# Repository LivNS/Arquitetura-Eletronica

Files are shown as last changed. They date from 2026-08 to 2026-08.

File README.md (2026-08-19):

# Carrinho-robô — Project-based Maker Lab (FIAP)

Engenharia de Software, disciplina Project-based Maker Lab (Profª Dra. Gedeane G. S. Kenshima).

**Integrantes:** 
- Debora da Silva Amaral - RM 550412 
- Eduardo Pielich - RM 99767 
- Livia Namba Seraphim - RM 97819 

## O que é

Carrinho-robô de duas rodas com tração diferencial, controlado sem fio pelo celular e com parada automática por sensor ultrassônico.

- **Plataforma:** ESP32 DevKit V1
- **Controle:** Wi-Fi — o ESP32 sobe um servidor web e o celular controla pelo navegador
- **Sensor:** HC-SR04 (para automaticamente a menos de 20 cm de um obstáculo)
- **Driver:** ponte H L298N
- **Alimentação:** 2 × 18650 (7,4 V) com regulador step-down 5 V para a lógica

## Estrutura

```
/hardware
  /arquitetura      diagramas de blocos, alimentação e layout físico (SVG)
  /componentes      lista de componentes, pinagem e consumo
/cad
  /stl              chassi exportado para impressão/corte (v0.1, v0.2 …)
  /fonte            modelo paramétrico em OpenSCAD
/src
  codigo.ino        firmware (ESP32 + Wi-Fi + ultrassônico)
/docs
  changelog-chassi.md    o que mudou da V0.1 para a V0.2
  mudancas-codigo.md     o que o grupo acrescentou ao código da aula
  testes.md              roteiro de teste incremental
  /registro-testes       fotos e vídeos dos testes
```

## Arquitetura

| Diagrama | Arquivo |
|---|---|
| Blocos (sinais e pinos) | [`hardware/arquitetura/diagrama-blocos.svg`](hardware/arquitetura/diagrama-blocos.svg) |
| Alimentação | [`hardware/arquitetura/diagrama-alimentacao.svg`](hardware/arquitetura/diagrama-alimentacao.svg) |
| Layout físico e cabos | [`hardware/arquitetura/layout-fisico.svg`](hardware/arquitetura/layout-fisico.svg) |

## Como rodar

1. Instalar a IDE Arduino e adicionar o suporte ao ESP32 (Gerenciador de Placas → `esp32` by Espressif).
2. Selecionar a placa **ESP32 Dev Module** e a porta COM correspondente.
3. Abrir `/src/codigo.ino` e preencher `ssid` e `password` com a rede Wi-Fi **de 2,4 GHz** (o ESP32 não enxerga 5 GHz).
4. Gravar, abrir o monitor serial em **115200** e anotar o IP que aparece.
5. Com o celular na mesma rede, acessar `http://<IP>` no navegador.

Antes do primeiro teste com os motores, seguir o roteiro de [`docs/testes.md`](docs/testes.md) com as rodas fora do chão.

## Escolha do controle sem fio

A aula apresentou três caminhos (Wi-Fi, ESP32-BLE e Arduino+HC-05). O grupo adotou o **controle via Wi-Fi** (opção 1, slide 7): não exige instalar nenhum app no celular — basta abrir o IP do ESP32 no navegador — e permite exibir a leitura do sensor na mesma tela do controle.

O código parte do que foi apresentado nos slides 8 a 13; os acréscimos do grupo estão marcados com `// [GRUPO]` e listados em [`docs/mudancas-codigo.md`](docs/mudancas-codigo.md).

## Estado atual

- [x] Chassi V0.2 definido
- [x] Diagramas de blocos e alimentação
- [x] Firmware com movimento, Wi-Fi e sensor
- [x] Sensor ultrassônico integrado ao código
- [ ] Testes incrementais registrados (`docs/testes.md`)
- [ ] STL da V0.2 exportado para `/cad/stl`

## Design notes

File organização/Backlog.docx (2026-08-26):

Backlog

Project-based Maker Lab — FIAP

Lista de tarefas derivadas do MoSCoW, organizadas para alimentar o Kanban. As colunas Responsável e Status devem ser preenchidas conforme cada item for assumido pelo time. Os identificadores (IDs) devem permanecer estáveis — sem renumeração — para preservar o histórico do projeto.

Convenção de status: A fazer · Em andamento · Bloqueada · Em revisão · Concluída

# Hardware

ID | Tarefa | Prioridade | Responsável | Status | Observação
HW-01 | Definir lista final de componentes e conferir com o kit recebido | Must | Debora | A fazer | ver lista-componentes.md
HW-02 | Montar circuito na bancada (sem chassi) para validar ligação | Must | Debora | A fazer | pré-requisito do MVP
HW-03 | Exportar e imprimir/cortar o chassi V0.2 | Must | Livia | A fazer | depende de CAD-01
HW-04 | Fixar motores, roda boba e suporte de bateria no chassi | Must | Debora | A fazer | depende de HW-03
HW-05 | Montar divisor resistivo do ECHO do HC-SR04 | Must | Eduardo | A fazer | protoboard pequena
HW-06 | Organizar cabos (canaletas, abraçadeiras) | Should | Livia | A fazer | depende de HW-04
HW-07 | Medir autonomia real da bateria | Should | Eduardo | A fazer | depende do carrinho montado
HW-08 | Avaliar posição de um segundo sensor (lateral) | Could | Debora | A fazer | apenas se houver tempo disponível

# CAD

ID | Tarefa | Prioridade | Responsável | Status | Observação
CAD-01 | Revisar chassi V0.1 → V0.2 conforme changelog-chassi.md | Must | Livia | Concluída | fonte: cad/fonte/chassi_v0.2.scad
CAD-02 | Exportar STL da V0.2 | Must | Debora | A fazer | salvar em cad/stl/chassi_v0.2.stl
CAD-03 | Conferir furação depois da primeira montagem física | Should | Eduardo | A fazer | depende de HW-04

# Firmware

ID | Tarefa | Prioridade | Responsável | Status | Observação
FW-01 | Adaptar código-base do slide (Wi-Fi) com credenciais do grupo | Must | Eduardo | Concluída | src/codigo.ino
FW-02 | Integrar leitura do HC-SR04 | Must | Eduardo | Concluída | marcado com // [GRUPO]
FW-03 | Implementar parada automática < 20 cm | Must | Eduardo | Concluída | só bloqueia o comando FRENTE
FW-04 | Implementar failsafe de conexão | Should | Eduardo | Concluída | timeout de 1,5 s
FW-05 | Exibir distância na página de controle | Should | Debora | Concluída | rota /distancia
FW-06 | Calibrar faixa de PWM mínimo (motor não sai do lugar) | Should | Debora | A fazer | depende de HW-02
FW-07 | Revisar mudancas-codigo.md para bater com o código final | Must | Eduardo | A fazer | atualizar antes de cada entrega

# Testes

ID | Tarefa | Prioridade | Responsável | Status | Observação
TST-01 | Executar os 15 passos de testes.md | Must | Debora | A fazer | depende de HW-02 e FW-01..05
TST-02 | Gravar vídeo/foto de cada passo em docs/registro-testes/ | Must | Livia | A fazer | mesmo ID do teste no nome do arquivo
TST-03 | Teste completo no chão com obstáculo real | Must | Debora | A fazer | depende de HW-04, HW-06

# Documentação e organização

ID | Tarefa | Prioridade | Responsável | Status | Observação
DOC-01 | Preencher README.md com integrantes e estado atual | Must | Livia | A fazer
DOC-02 | Preencher planilha de custos com preços reais | Must | Livia | A fazer | planilha-custos.xlsx
DOC-03 | Manter o Kanban atualizado a cada reunião do grupo | Should | Livia | A fazer | Kanban.docx
DOC-04 | Revisar MoSCoW antes da entrega final | Should | Livia | A fazer | ver seção Revisão

# Diretrizes de uso

- Toda nova tarefa recebe um identificador sequencial dentro de sua categoria (HW-09, FW-08, etc.).
- Ao assumir uma tarefa, o responsável deve atualizar o status neste documento e mover o cartão correspondente no Kanban.
- Tarefas com status Bloqueada devem indicar, na coluna Observação, o motivo do bloqueio.

Project-based Maker Lab — Carrinho-robô · página 1

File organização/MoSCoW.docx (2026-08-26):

MoSCoW — priorização das funcionalidades

Project-based Maker Lab — FIAP

Classificação de todas as funcionalidades previstas para o carrinho, com o objetivo de orientar a alocação do tempo do grupo. As funcionalidades Must compõem o MVP (ver MVP.docx); Should e Could serão desenvolvidas caso haja tempo disponível; Won't permanece documentado para que não seja esquecido nem rediscutido próximo ao prazo de entrega.

# Must have — requisitos obrigatórios

Funcionalidade | Justificativa
Motores respondem a FRENTE / RÉ / ESQUERDA / DIREITA / PARAR | Constitui o deslocamento do carrinho — sem essa funcionalidade não há projeto
Servidor Wi-Fi no ESP32 com página de controle | Forma de controle definida pelo grupo (slide 7, opção 1)
Leitura do sensor HC-SR04 | Entregável explícito da Aula 16
Parada automática abaixo de 20 cm | Requisito de segurança definido pelo grupo
Chassi montado e motores fixados | Sem estrutura física não há como realizar testes reais
Alimentação por bateria, sem depender de USB do computador | Necessária para que o carrinho se desloque livremente

# Should have — relevante, mas não impede a entrega

Funcionalidade | Justificativa
Controle de velocidade pelo slider | Já presente no código de referência da aula, com custo de manutenção baixo
Failsafe (interrupção ao perder conexão) | Reduz o risco de acidente durante a demonstração, ainda que não seja critério de avaliação direto
Organização de cabos com abraçadeiras e canaletas | Torna a montagem mais confiável e com melhor acabamento
Exibição da distância lida na própria página | Facilita a validação do sensor sem necessidade do monitor serial

# Could have — desejável, se houver tempo disponível

Funcionalidade | Justificativa
LED indicando status (conectado / obstáculo / parado) | Melhora a demonstração, sem impacto na funcionalidade principal
Segundo sensor (lateral ou traseiro) | Amplia a segurança, mas exige GPIOs adicionais e alteração no chassi
Registro do consumo de bateria em tempo real | Relevante, porém fora do escopo previsto pela disciplina
Alternativas de controle (BLE, HC-05) mantidas como referência | Documenta o processo de decisão do grupo, sem uso na entrega final

# Won't have — fora desta entrega

Funcionalidade | Motivo da exclusão
Navegação autônoma / desvio automático de rota | Fora do escopo abordado pela disciplina até o momento
Aplicativo dedicado, fora do navegador | O controle via Wi-Fi e navegador já atende ao requisito, sem custo adicional de desenvolvimento
Múltiplos sensores simultâneos | A complexidade de fiação e de GPIOs não se justifica dentro do prazo disponível
(a definir pelo grupo) | (a definir pelo grupo)

# Revisão

Esta classificação deve ser revisada a cada ciclo do Kanban. Itens Should/Could concluídos devem ser registrados no changelog; itens que não avançarem até a penúltima entrega serão automaticamente reclassificados como Won't.

Project-based Maker Lab — Carrinho-robô · página 1

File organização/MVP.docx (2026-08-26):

MVP do carrinho-robô

Project-based Maker Lab — FIAP

# Definição de MVP

O produto final do projeto consiste no carrinho em movimento, respondendo a comandos via Wi-Fi e interrompendo o deslocamento automaticamente ao se aproximar de um obstáculo. O MVP (Minimum Viable Product) corresponde ao menor subconjunto dessas funcionalidades que já demonstra a solução funcionando de ponta a ponta, ainda que sem acabamento — sem chassi definitivo e sem organização de cabos. Seu propósito é permitir uma demonstração antecipada da viabilidade técnica, de modo que eventuais problemas estruturais (por exemplo, motor sem torque suficiente, ou rede Wi-Fi indisponível no local da apresentação) sejam identificados com antecedência, e não na véspera da entrega final.

# Critério de produto minimamente funcional (MVP)

O MVP será considerado atingido quando, com o carrinho posicionado sobre a bancada (rodas suspensas, sem contato com o solo), as seguintes condições forem verificadas:

☐ Os dois motores giram nos dois sentidos, comandados pelo ESP32

☐ A página Wi-Fi é acessada pelo celular e os botões FRENTE / RÉ / ESQUERDA / DIREITA / PARAR respondem corretamente

☐ O sensor HC-SR04 realiza leituras estáveis de distância, compatíveis com medição feita por trena

☐ O carrinho interrompe o movimento automaticamente ao detectar obstáculo a menos de 20 cm, mesmo com o comando FRENTE ativo

Critério de aceite do MVP: é possível registrar um vídeo de até 30 segundos demonstrando as quatro condições acima, ainda que com fiação provisória e sem o chassi V0.2 impresso.

Data alvo: 20/09/2026

# Critério de conclusão

O projeto será considerado concluído quando, além do MVP, as seguintes condições forem atendidas:

☐ Chassi V0.2 (ou versão posterior) montado, com todos os componentes fixados

☐ Cabeamento organizado conforme hardware/arquitetura/layout-fisico.svg (canaletas, abraçadeiras)

☐ Roteiro completo de docs/testes.md executado e registrado em docs/registro-testes/

☐ Carrinho em funcionamento sobre piso real, percorrendo trajeto com pelo menos um obstáculo

☐ Autonomia da bateria medida e registrada em hardware/componentes/lista-componentes.md

☐ Repositório do GitHub com todas as pastas de /organização e /hardware devidamente preenchidas

☐ Apresentação/demonstração ensaiada previamente à data de entrega

Critério de aceite da versão final: um professor ou integrante de outro grupo consegue montar o carrinho e reproduzir o teste utilizando apenas as instruções do README, sem necessidade de esclarecimentos adicionais do grupo.

Data alvo: 20/09/2026

# Itens fora do escopo

Funcionalidades não abordadas em aula e que o grupo optou por não desenvolver nesta etapa, de modo a concentrar esforços no que será avaliado:

- Navegação autônoma sem intervenção humana
- Sensores adicionais (lateral, traseiro)
- Aplicativo dedicado, fora do navegador

Project-based Maker Lab — Carrinho-robô · página 1

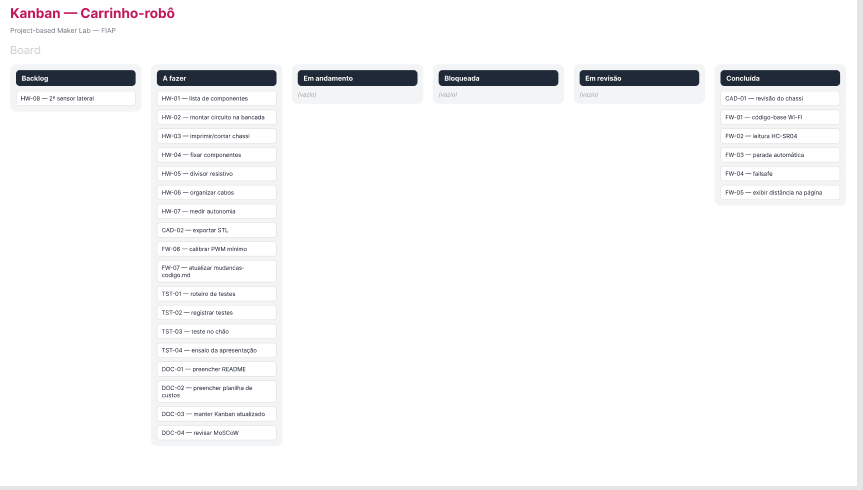
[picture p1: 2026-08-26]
organização/Kanban.png

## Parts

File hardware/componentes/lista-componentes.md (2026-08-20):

# Lista de componentes (BOM)

## 1. Eletrônica

| # | Componente | Modelo | Qtd | Tensão | Consumo típico | Função no projeto |
|---|---|---|---|---|---|---|
| 1 | Microcontrolador | ESP32 DevKit V1 (30 ou 38 pinos) | 1 | 5 V no VIN / 3,3 V lógica | ~80 mA (picos de 250 mA no Wi-Fi) | servidor web + controle |
| 2 | Driver de motor | Ponte H L298N | 1 | 5–35 V | ~36 mA + motores | aciona os dois motores |
| 3 | Sensor de distância | HC-SR04 | 1 | 5 V | ~15 mA | parada automática frontal |
| 4 | Regulador | step-down MP1584 ou LM2596 | 1 | entrada 7–28 V → 5 V | até 1 A | alimenta o ESP32 |
| 5 | Motor DC | TT com redução 1:48 | 2 | 3–6 V | ~150 mA livre / ~1,2 A travado | tração |
| 6 | Bateria | Li-ion 18650 2200 mAh | 2 | 3,7 V cada (7,4 V em série) | — | fonte única |
| 7 | Suporte de bateria | 2 × 18650 com fios | 1 | — | — | fixação das células |
| 8 | Chave | gangorra KCD1 2 pinos | 1 | — | — | liga/desliga geral |
| 9 | Resistores | 1 kΩ e 2 kΩ | 1 de cada | — | — | divisor no ECHO do HC-SR04 |
| 10 | Fusível + porta-fusível | 2 A vidro 5×20 mm | 1 | — | — | proteção (recomendado) |

## 2. Mecânica e montagem

| # | Item | Especificação | Qtd |
|---|---|---|---|
| 11 | Chassi | 200 × 150 × 4 mm — ver `/cad` | 1 |
| 12 | Roda | 65 mm, eixo TT | 2 |
| 13 | Roda boba | esfera metálica ou rodízio | 1 |
| 14 | Parafusos + porcas | M3 × 10 mm | ~20 |
| 15 | Espaçadores | latão M3 15 mm | 8 |
| 16 | Abraçadeiras | 2,5 × 100 mm | ~30 |
| 17 | Espiral organizador | 6 mm | 1 m |
| 18 | Jumpers | macho-fêmea e macho-macho | ~40 |
| 19 | Protoboard pequena | 170 pontos (para o divisor) | 1 |

## 3. Mapa de pinos — ESP32 (versão Wi-Fi, `/src/codigo.ino`)

Pinagem do L298N conforme a tabela do slide 7 da Aula 16.

| GPIO | Direção | Vai para | Função | Cor sugerida |
|---|---|---|---|---|
| 27 | saída | L298N IN1 | sentido motor esquerdo | branco |
| 26 | saída | L298N IN2 | sentido motor esquerdo | branco |
| 14 | saída PWM | L298N ENA | velocidade motor esquerdo | laranja |
| 33 | saída | L298N IN3 | sentido motor direito | cinza |
| 25 | saída | L298N IN4 | sentido motor direito | cinza |
| 32 | saída PWM | L298N ENB | velocidade motor direito | laranja |
| 5 | saída | HC-SR04 TRIG | dispara o pulso | amarelo |
| 18 | entrada | HC-SR04 ECHO **via divisor 1 kΩ/2 kΩ** | mede o retorno | roxo |
| VIN | alimentação | saída do regulador 5 V | entrada de energia | vermelho |
| GND | referência | barramento comum | terra do sistema | preto |

**Total:** 8 GPIOs. Evitar os GPIOs 6–11 (flash SPI) e os pinos de boot (0, 2, 12, 15).

## 4. Consumo estimado

| Bloco | Corrente |
|---|---|
| 2 motores em regime | ~600 mA |
| 2 motores em pico | ~2,4 A |
| ESP32 + HC-SR04 | ~100 mA (pico 270 mA transmitindo) |
| **Pico total** | **~2,7 A** |

Com 2200 mAh e consumo médio de ~800 mA, a autonomia estimada é de **2 a 2,5 horas**. ✏️ Medir na prática e registrar.

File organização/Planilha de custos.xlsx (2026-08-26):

Planilha de custos — Carrinho-robô
# | Categoria | Item | Loja / Link | Preço unitário (R$) | Quantidade | Valor estimado (R$) | Observação
1 | Eletrônica | ESP32 DevKit V1 (30 ou 38 pinos) | https://www.google.com/search?q=esp32+devkit+v1+comprar | R$35.00 | 1 | R$35.00
2 | Eletrônica | Ponte H L298N | https://www.google.com/search?q=modulo+ponte+h+l298n+comprar | R$18.00 | 1 | R$18.00
3 | Eletrônica | Sensor ultrassônico HC-SR04 | https://www.google.com/search?q=sensor+hc-sr04+comprar | R$12.00 | 1 | R$12.00
4 | Eletrônica | Regulador step-down (MP1584/LM2596) | https://www.google.com/search?q=regulador+step+down+lm2596+comprar | R$10.00 | 1 | R$10.00
5 | Eletrônica | Motor DC TT com redução 1:48 | https://www.google.com/search?q=motor+dc+tt+redução+comprar | R$15.00 | 2 | R$30.00
6 | Eletrônica | Bateria Li-ion 18650 2200 mAh | https://www.google.com/search?q=bateria+18650+2200mah+comprar | R$22.00 | 2 | R$44.00
7 | Eletrônica | Suporte 2x18650 com fios | https://www.google.com/search?q=suporte+bateria+18650+comprar | R$8.00 | 1 | R$8.00
8 | Eletrônica | Chave gangorra KCD1 2 pinos | https://www.google.com/search?q=chave+gangorra+kcd1+comprar | R$3.50 | 1 | R$3.50
9 | Eletrônica | Resistores 1k e 2k (kit sortido) | https://www.google.com/search?q=kit+resistores+comprar | R$15.00 | 1 | R$15.00
10 | Eletrônica | Fusível + porta-fusível 2A | https://www.google.com/search?q=porta+fusivel+2a+comprar | R$6.00 | 1 | R$6.00
11 | Mecânica | Placa acrílico/MDF para chassi (200x150x4mm) | https://www.google.com/search?q=placa+acrilico+corte+a+laser+comprar | R$25.00 | 1 | R$25.00
12 | Mecânica | Roda 65mm compatível com eixo TT | https://www.google.com/search?q=roda+65mm+eixo+tt+comprar | R$8.00 | 2 | R$16.00
13 | Mecânica | Roda boba (esfera ou rodízio) | https://www.google.com/search?q=roda+boba+robo+comprar | R$6.00 | 1 | R$6.00
14 | Mecânica | Parafusos + porcas M3x10 | https://www.google.com/search?q=kit+parafuso+m3+comprar | R$12.00 | 1 | R$12.00
15 | Mecânica | Espaçadores latão M3 15mm | https://www.google.com/search?q=espacador+latao+m3+comprar | R$10.00 | 1 | R$10.00
16 | Organização de cabos | Abraçadeiras (fita Hellerman / enforca-gato) | https://www.google.com/search?q=abracadeira+enforca+gato+comprar | R$8.00 | 1 | R$8.00
17 | Organização de cabos | Espiral organizador de cabo 6mm | https://www.google.com/search?q=espiral+organizador+cabo+comprar | R$7.00 | 1 | R$7.00
18 | Organização de cabos | Jumpers macho-fêmea e macho-macho | https://www.google.com/search?q=kit+jumper+jacare+comprar | R$14.00 | 1 | R$14.00
19 | Ferramentas/consumo | Protoboard pequena 170 pontos | https://www.google.com/search?q=protoboard+170+pontos+comprar | R$9.00 | 1 | R$9.00
20 | Ferramentas/consumo | item adicional do grupo |  | R$0.00 | 0 | R$0.00
 |  |  |  |  | TOTAL GERAL | R$288.50
 | Subtotal por categoria
 | Categoria | Valor (R$)
 | Eletrônica | R$181.50
 | Ferramentas/consumo | R$9.00
 | Mecânica | R$69.00
 | Organização de cabos | R$29.00
 | Legenda
 | Célula azul / fundo amarelo | entrada: editar com o preço e a quantidade reais
 | Célula preta | calculada por fórmula, não editar diretamente
 | Fonte dos itens | Baseado em hardware/componentes/lista-componentes.md — preços de exemplo

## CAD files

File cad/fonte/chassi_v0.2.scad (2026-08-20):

// ============================================================
//  Chassi do carrinho-robo - V0.2
//  Project-based Maker Lab (FIAP)
//  Ferramenta: OpenSCAD
//
//  Como exportar o STL:
//    1. abrir este arquivo no OpenSCAD
//    2. F6 (render) e depois F7 (export STL)
//    3. salvar em /cad/stl/chassi_v0.2.stl
// ============================================================

/* [Placa principal] */
comprimento   = 200;   // mm
largura       = 150;   // mm
espessura     = 4;     // mm
raio_canto    = 15;    // mm

/* [Motores] */
dist_eixo_frente = 70;   // distancia da frente ate o centro do eixo
larg_motor       = 23;   // largura do motor amarelo TT
comp_motor       = 38;
folga_roda       = 12;   // recorte lateral pra roda passar

/* [Furacao] */
furo_m3       = 3.4;    // passagem folgada pra parafuso M3
furo_abracadeira_l = 8; // rasgo pra abracadeira (enforca-gato)
furo_abracadeira_a = 3;
$fn = 48;

// ------------------------------------------------------------
module placa_base() {
    hull() {
        for (x = [raio_canto, comprimento - raio_canto],
             y = [raio_canto, largura - raio_canto])
            translate([x, y, 0]) cylinder(h = espessura, r = raio_canto);
    }
}

module recortes_roda() {
    for (y = [-1, largura - folga_roda + 1])
        translate([dist_eixo_frente - comp_motor/2, y, -1])
            cube([comp_motor, folga_roda, espessura + 2]);
}

module furos_motor() {
    // pares de furos M3 pra prender as braadeiras/suportes dos motores TT
    for (y = [folga_roda + 6, largura - folga_roda - 6])
        for (dx = [-14, 14])
            translate([dist_eixo_frente + dx, y, -1])
                cylinder(h = espessura + 2, d = furo_m3);
}

module furos_eletronica() {
    // grade de furos M3 a cada 15 mm - permite reposicionar Arduino, L298N e regulador
    for (x = [60 : 15 : comprimento - 40])
        for (y = [30 : 15 : largura - 30])
            translate([x, y, -1]) cylinder(h = espessura + 2, d = furo_m3);
}

module furos_bateria() {
    // fixacao do suporte 2x18650, centralizado e atras do eixo
    for (dx = [-32, 32])
        for (dy = [-22, 22])
            translate([comprimento - 60 + dx, largura/2 + dy, -1])
                cylinder(h = espessura + 2, d = furo_m3);
}

module rasgos_abracadeira() {
    // canaletas laterais: esquerda = alimentacao, direita = sinal
    for (y = [14, largura - 14])
        for (x = [40 : 25 : comprimento - 30])
            translate([x, y - furo_abracadeira_a/2, -1])
                cube([furo_abracadeira_l, furo_abracadeira_a, espessura + 2]);
}

module suporte_sensor() {
    // aba frontal vertical pro HC-SR04 (dois furos de 16 mm de centro a centro)
    translate([6, largura/2 - 25, espessura])
        difference() {
            cube([4, 50, 22]);
            for (dy = [11, 39])
                translate([-1, dy, 12]) rotate([0, 90, 0]) cylinder(h = 6, d = 16.2);
        }
}

module furo_roda_boba() {
    for (dx = [-10, 10])
        translate([comprimento - 25 + dx, largura/2, -1])
            cylinder(h = espessura + 2, d = furo_m3);
}

// ------------------------------------------------------------
module chassi() {
    difference() {
        placa_base();
        recortes_roda();
        furos_motor();
        furos_eletronica();
        furos_bateria();
        rasgos_abracadeira();
        furo_roda_boba();
    }
    suporte_sensor();
}

chassi();

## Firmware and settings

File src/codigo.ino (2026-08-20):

/*
 * ============================================================
 *  Carrinho-robo - Project-based Maker Lab (FIAP)
 *  Aula 16 - Controle sem fio (WiFi) - opcao 1
 *
 *  BASE: codigo apresentado nos slides 8 a 13 da Aula 16
 *        (fonte citada no slide: randomnerdtutorials.com/esp32-wi-fi-car-robot-arduino)
 *        Mantidos os nomes de variaveis, a pinagem da tabela do slide 7
 *        e a estrutura de rotas/handlers do original.
 *
 *  ACRESCIMOS DO GRUPO (todos marcados com "// [GRUPO]"):
 *    1. sensor ultrassonico HC-SR04
 *    2. parada automatica com obstaculo a menos de 20 cm
 *    3. leitura da distancia exibida na propria pagina
 *    4. failsafe: para os motores se a pagina parar de responder
 *  Ver docs/testes.md para o roteiro de teste incremental.
 * ============================================================
 */

#include <WiFi.h>
#include <WebServer.h>

// Replace with your network credentials
const char* ssid     = "COLOQUE_SEU_SSID";      // ✏️ preencher
const char* password = "COLOQUE_SUA_SENHA";     // ✏️ preencher

// Create an instance of the WebServer on port 80
WebServer server(80);

// Motor 1 - pinagem da tabela do slide 7
int motor1Pin1 = 27;
int motor1Pin2 = 26;
int enable1Pin = 14;

// Motor 2
int motor2Pin1 = 33;
int motor2Pin2 = 25;
int enable2Pin = 32;

// Setting PWM properties
const int freq = 30000;
const int resolution = 8;
int dutyCycle = 0;

String valueString = String(0);

// [GRUPO] pinos do sensor ultrassonico
const int trigPin = 5;
const int echoPin = 18;              // ECHO devolve 5 V -> divisor 1k/2k ate o GPIO

// [GRUPO] estado usado pela trava de seguranca e pelo failsafe
const int DIST_PARADA_CM = 20;
const unsigned long TIMEOUT_COMANDO_MS = 1500;
int distanciaCm = -1;
bool andandoParaFrente = false;
unsigned long ultimaLeitura = 0;
unsigned long ultimoComando = 0;

// ============================================================
// [GRUPO] leitura do HC-SR04
// ============================================================
int medirDistancia() {
  digitalWrite(trigPin, LOW);
  delayMicroseconds(2);
  digitalWrite(trigPin, HIGH);
  delayMicroseconds(10);
  digitalWrite(trigPin, LOW);

  unsigned long duracao = pulseIn(echoPin, HIGH, 25000UL);   // timeout ~4 m
  if (duracao == 0) return -1;                               // sem eco
  int cm = duracao / 58;
  return (cm > 300) ? -1 : cm;
}

// [GRUPO] true quando ha obstaculo perto demais
bool caminhoBloqueado() {
  return (distanciaCm > 0 && distanciaCm < DIST_PARADA_CM);
}

// ============================================================
//  PAGINA WEB  (handleRoot do slide 9, com a linha da distancia)
// ============================================================
void handleRoot() {
  const char html[] PROGMEM = R"rawliteral(
<!DOCTYPE HTML><html>
<head>
  <meta name="viewport" content="width=device-width, initial-scale=1">
  <link rel="icon" href="data:,">
  <style>
    html { font-family: Helvetica; display: inline-block; margin: 0px auto; text-align: center; }
    .button { -webkit-user-select: none; -moz-user-select: none; -ms-user-select: none;
              user-select: none; background-color: #4CAF50; border: none; color: white;
              padding: 12px 28px; text-decoration: none; font-size: 26px; margin: 1px;
              cursor: pointer; }
    .button2 { background-color: #555555; }
    #distancia { font-size: 22px; font-weight: bold; }
  </style>
  <script>
    function moveForward() { fetch('/forward'); }
    function moveLeft()    { fetch('/left'); }
    function stopRobot()   { fetch('/stop'); }
    function moveRight()   { fetch('/right'); }
    function moveReverse() { fetch('/reverse'); }
    function updateMotorSpeed(pos) {
      document.getElementById('motorSpeed').innerHTML = pos;
      fetch(`/speed?value=${pos}`);
    }
    // [GRUPO] atualiza a distancia e serve de heartbeat para o failsafe
    setInterval(() => {
      fetch('/distancia').then(r => r.text()).then(t => {
        document.getElementById('distancia').innerHTML = (t == -1) ? '--' : t;
      });
    }, 400);
  </script>
</head>
<body>
  <h1>ESP32 Motor Control</h1>
  <p><button class="button" onclick="moveForward()">FORWARD</button></p>
  <div style="clear: both;">
    <p>
      <button class="button" onclick="moveLeft()">LEFT</button>
      <button class="button button2" onclick="stopRobot()">STOP</button>
      <button class="button" onclick="moveRight()">RIGHT</button>
    </p>
  </div>
  <p><button class="button" onclick="moveReverse()">REVERSE</button></p>
  <p>Motor Speed: <span id="motorSpeed">0</span></p>
  <input type="range" min="0" max="100" step="25" id="motorSlider"
         oninput="updateMotorSpeed(this.value)" value="0"/>
  <p>Distancia: <span id="distancia">--</span> cm</p>
</body>
</html>)rawliteral";
  server.send(200, "text/html", html);
}

// ============================================================
//  HANDLERS DE MOVIMENTO  (slides 10 e 11)
// ============================================================
void handleForward() {
  Serial.println("Forward");
  ultimoComando = millis();                  // [GRUPO]
  if (caminhoBloqueado()) {                  // [GRUPO] nao deixa avancar contra o obstaculo
    Serial.println("Bloqueado pelo sensor");
    handleStop();
    return;
  }
  andandoParaFrente = true;                  // [GRUPO]
  digitalWrite(motor1Pin1, LOW);
  digitalWrite(motor1Pin2, HIGH);
  digitalWrite(motor2Pin1, LOW);
  digitalWrite(motor2Pin2, HIGH);
  server.send(200);
}

void handleLeft() {
  Serial.println("Left");
  ultimoComando = millis();                  // [GRUPO]
  andandoParaFrente = false;                 // [GRUPO]
  digitalWrite(motor1Pin1, LOW);
  digitalWrite(motor1Pin2, LOW);
  digitalWrite(motor2Pin1, LOW);
  digitalWrite(motor2Pin2, HIGH);
  server.send(200);
}

void handleRight() {
  Serial.println("Right");
  ultimoComando = millis();                  // [GRUPO]
  andandoParaFrente = false;                 // [GRUPO]
  digitalWrite(motor1Pin1, LOW);
  digitalWrite(motor1Pin2, HIGH);
  digitalWrite(motor2Pin1, LOW);
  digitalWrite(motor2Pin2, LOW);
  server.send(200);
}

void handleReverse() {
  Serial.println("Reverse");
  ultimoComando = millis();                  // [GRUPO]
  andandoParaFrente = false;                 // [GRUPO]
  digitalWrite(motor1Pin1, HIGH);
  digitalWrite(motor1Pin2, LOW);
  digitalWrite(motor2Pin1, HIGH);
  digitalWrite(motor2Pin2, LOW);
  server.send(200);
}

void handleStop() {
  Serial.println("Stop");
  ultimoComando = millis();                  // [GRUPO]
  andandoParaFrente = false;                 // [GRUPO]
  digitalWrite(motor1Pin1, LOW);
  digitalWrite(motor1Pin2, LOW);
  digitalWrite(motor2Pin1, LOW);
  digitalWrite(motor2Pin2, LOW);
  server.send(200);
}

// [GRUPO] usada pelo loop, quando nao ha requisicao para responder
void pararMotores() {
  andandoParaFrente = false;
  digitalWrite(motor1Pin1, LOW);
  digitalWrite(motor1Pin2, LOW);
  digitalWrite(motor2Pin1, LOW);
  digitalWrite(motor2Pin2, LOW);
}

// ============================================================
//  VELOCIDADE  (handleSpeed do slide 11)
// ============================================================
void handleSpeed() {
  ultimoComando = millis();                  // [GRUPO]
  if (server.hasArg("value")) {
    valueString = server.arg("value");
    int value = valueString.toInt();
    if (value == 0) {
      ledcWrite(enable1Pin, 0);
      ledcWrite(enable2Pin, 0);
      pararMotores();
    } else {
      dutyCycle = map(value, 25, 100, 200, 255);
      ledcWrite(enable1Pin, dutyCycle);
      ledcWrite(enable2Pin, dutyCycle);
      Serial.println("Motor speed set to " + String(value));
    }
  }
  server.send(200);
}

// [GRUPO] rota nova: devolve a distancia lida para a pagina
void handleDistancia() {
  ultimoComando = millis();
  server.send(200, "text/plain", String(distanciaCm));
}

// ============================================================
//  SETUP  (slide 12)
// ============================================================
void setup() {
  Serial.begin(115200);

  // Set the Motor pins as outputs
  pinMode(motor1Pin1, OUTPUT);
  pinMode(motor1Pin2, OUTPUT);
  pinMode(motor2Pin1, OUTPUT);
  pinMode(motor2Pin2, OUTPUT);

  // [GRUPO] pinos do sensor
  pinMode(trigPin, OUTPUT);
  pinMode(echoPin, INPUT);

  // Configure PWM Pins  (API do core ESP32 3.x, como no slide)
  ledcAttach(enable1Pin, freq, resolution);
  ledcAttach(enable2Pin, freq, resolution);
  // Core 2.x? usar no lugar:
  //   ledcSetup(0, freq, resolution); ledcAttachPin(enable1Pin, 0);
  //   ledcSetup(1, freq, resolution); ledcAttachPin(enable2Pin, 1);

  // Initialize PWM with 0 duty cycle
  ledcWrite(enable1Pin, 0);
  ledcWrite(enable2Pin, 0);

  // Connect to Wi-Fi
  Serial.print("Connecting to ");
  Serial.println(ssid);
  WiFi.begin(ssid, password);
  while (WiFi.status() != WL_CONNECTED) {
    delay(500);
    Serial.print(".");
  }
  Serial.println("");
  Serial.println("WiFi connected.");
  Serial.println("IP address: ");
  Serial.println(WiFi.localIP());

  // Define routes  (slide 13)
  server.on("/",          handleRoot);
  server.on("/forward",   handleForward);
  server.on("/left",      handleLeft);
  server.on("/stop",      handleStop);
  server.on("/right",     handleRight);
  server.on("/reverse",   handleReverse);
  server.on("/speed",     handleSpeed);
  server.on("/distancia", handleDistancia);   // [GRUPO]

  // Start the server
  server.begin();
}

// ============================================================
//  LOOP  (slide 13 + acrescimos do grupo)
// ============================================================
void loop() {
  server.handleClient();

  // [GRUPO] leitura periodica do sensor, sem travar o servidor
  if (millis() - ultimaLeitura >= 60) {
    ultimaLeitura = millis();
    distanciaCm = medirDistancia();
  }

  // [GRUPO] trava de seguranca: so interrompe quem esta indo para frente
  if (andandoParaFrente && caminhoBloqueado()) {
    pararMotores();
    Serial.printf("OBSTACULO a %d cm - parado\n", distanciaCm);
  }

  // [GRUPO] failsafe: perdeu contato com o navegador -> para
  if (millis() - ultimoComando > TIMEOUT_COMANDO_MS) {
    pararMotores();
  }
}
